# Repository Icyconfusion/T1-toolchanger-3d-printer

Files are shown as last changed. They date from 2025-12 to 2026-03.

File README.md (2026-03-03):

# T1-toolchanger-3d-printer
A toolchanger 3d printer with large format build size and multiple tools for quick, easy multi-material printing that uses marlin as the firmware.


**Note to reviewer:** Since submitting project for review I have updated the BOM (haven't changed products, just updated the prices). The new bom is more than what was in the review, but I have multiple discounts and coupons (that I have also tested) which bring it back down to what I mentioned in review. Thank you :) Also, in regards to firmware, the entire marlin zip folder (must be a zip) is in the firmware folder, but I have copied all files that have been edited and/or relevant (e.g config and ino files) as well into the firmware folder for the reviewer to view. I was instructed to do it this way by other reviewers in similar projects. Thanks.

I made this project as I had been looking to make a 3d printer. I wanted to be able to print in different colours, without the added cost of AMS systems. It was also a good opportunity to learn about using programs like fusion and Kicad, which I have limited experience with, as well as learning about electronic components. I created this project without a guide, using my own ideas to combat problems, with some inspiration from existing products e.g using linear rods.

Note: The assembly files are too large to upload to Github directly. Instead I have put the assembly .step file and .f3z file into a zipped folder named: Printer assembly.zip 

I have also uploaded the same step file as a zipped folder called printer assembly Step.zip, and an STL file called printer assembly STL.zip, just to be sure.

The printer uses a swappable hotend mechanism to dock tools, removing the need to purge filament as in other multi-material systems. The idle toolheads sit on an aluminium extrusion. The X carriage, supported by a V slot extrusion, moves in and attaches to the toolhead, using kinematic couplings for repeatability. A magnetic pogo connector transfers power for the heter and thermistor.


Toolhead:



# **Assembly**

The printer assembly is made by aluminium extrusions forming a cube, with corner connectors for mounting.


To support the Y axis, V slot 2020 aluminium extrusions are used as rails holding a gantry, which in turn supports the X axis.
The Y axis is made up of two carriages, one either side of the X gantry. Each Y carriage uses a gantry plate with wheels to slide along the extrusions, making the Y motion. One carriage is an idler, which the belt loops around a pulley. The other carriage is the stepper motor carriage, which uses a Nema 17 motor to drive the X axis belt. Both carriages hold 90 degree connectors supporting the X extrusion.
Idler:

Stepper carriage:


The X carriage is made of two parts: the main carriage, and the toolhead. The main carriage holds the fan and the extruder stepper motor. When the carriage comes into dock, a fixed arm pushes the extruder idle arm to the side. The filament slides into the extruder,and when docking is complete, the spring loaded, idle arm pushes back into the filament, creating good tension. 


The fan is a 4010 fan, which sits to the side and blows cool air through the heatsink fins and also onto the part/top layer. 


The belt post is located behind the carriage.



The carriage sid of the coupling contains the 6mm smooth rods of the kinematic coupling. This is printed in two pieces, so that the rods can be put into grooves before the 'lid' of the coupling closes through screws. The pogo connector is also housed here.



The toolhead uses steel balls to push into the kinematic coupling. The male side of the pogo connector is on the toolhead.


The hotend mounts to the two holes in the middle.

The Z axis involves the motion of the bed up and down. Originally, I had planned to move the hotend throughout all 3 axis, and the bed was fixed. I encountered many issues with reliably and consistently achieving motion of the hotend without the risk of flexing, so I pivoted to a bed Z axis. A leadscrew and two 8mm linear rods are used on each side, connected to an aluminium profile by a nut block and 3d printed clamps.


The bed frame is a square made of aluminium extrusions, held together by 90 degree corner connectors. The 6mm aluminium print bed sits on top of that, threaded into T nuts in the profiles.





Toolchanging mechanism. Tools are held on the toolchanger rack, installed with T nuts on an aluminium profile. L shaped hooks hold the tools in place, using knobs on the tools.Wwhen the tool slides in sideways, the knob/tool will be separated from the carriage by the hook Then the carriage will move backwards, detaching the magnets in the connectors, and pulling the tool off the rack. To attach, it simply presses the carriage onto the tool, pushes it back and slides out. The magnets used in the connector and the balls should be enough to hold the tool in place, but in the event it is not, I can use print in place function in slicers to add in even stronger magnets in the centre (only if current magnet setup isn't strong enough - unlikely).




# **Electronics**


The printer uses a PCB motherboard to mount components including the MCU (Mega 2560), stepper drivers, LCD headers, and heater terminals. I decided on a 24v power supply as it was compatible with my heater. To give power to the PCB, I used a meanwell 24v 360W power supply.


This connects through wires to screw terminals on the board, which then distribute power across the PCB. Because of the power requirements, I decided to use a 4 layer PCB as I couldn't route signal traces through the power and GND traces. Using a 4 layer PCB is necessary to the peojwct due to the power layout of drivers, making signal traces impossible without a 3rd and 4th layer. The top and bottom layers of the PCB are the power layers. Power runs from the PSU input to the heater screw terminal, and throughout the board. It is converted to 5v through a buck converter. The Hotend heater is powered through a screw terminal, and controlled by the mosfet next to its terminal. The hotend fan is controlled by a header, it is in an always on state.


The signal traces from the drivers, limit switches, thermistor and LCD are on the second and third layers.


The MCU is a mega 2560. I chose this because of its large availability of pins, enabling future upgrades and fitting all components. The stepper drivers are A4988s, which have microstepping up to 1/16. All microstep pins are connected to 5v, making the configuration 1/16. The limit switches, thermistor and lcd connect to headers.

The power for the stepper drivers is 24v. To reduce the effect of spikes, a small 100nf capacitor is used between the 24v and gnd supply of each driver. For larger spikes, a 100 uF capacitor is also placed between 24v and gnd of each driver.


The LCD is the main user interface of the printer. I am using the BIGTREETECH TFT35 V3.0 Touch Screen from BigTreeTech which has wifi capability and is 3.5". I chose this LCD as it only uses 2 pins on the MCU (TX and RX), has an SD card, and is touchscreen. It is possible to mount the LCD separately to the motherboard, and run a cable between the two, enabling you to set it up however you like. LCD Header:


The Motherboard and PSU are not fixed components to the printer and can be placed wherever suitable as long as cabling reaches. (I already have a case at home for my pcb from older projects).

### Schematic







# **Firmware**

The printer uses the latest version of marlin firmware, which enables the use of G-code. The general firmware of the printer is fairly standard and straightforward, as marlin is just configured to the printer dimensions and layout. The firmware has been edited to match the printer configuration with things like pin usage, limits, dimensions, and rough speeds/acceleration (these will require testing following assembly).

However, the printer being a toolchanger introduces a unique element to the firmware in the connection and preparation of multiple toolheads. To simplify firmware and general electronics, I decided on having 'hot-swappable' toolheads that connect through pogo connectors. Because of this, the firmware views it as one hotend when it comes to heating the temperature monitoring. In this aspect, the printer appears as standard. To facilitate toolchanges though, special G-code is required to move the carriage into specific positions. This is most effectively achieved through pre and post g-code in the slicer per tool. The main idea of the toolchange G-code is that the empty carriage moves into alignment with the passive tool, moves forward to latch on, and then returns to the print area. When returning a tool to the standby dock, it is the same idea in reverse, where it moves into a specific position, pushes the tool into the dock, and returns to pick up another tool. This is the series of G-code to paste into the slicer pre and post processing:

Pre:

M1 X(Tool X value) Y440 F6000

M1 X(Tool X value) Y480 F2000

M1 X(Tool X value + 60) Y480 F2000

M1 X(Tool X value + 60) Y440 F2000

Post:

M1 X(Tool X value + 60) Y440 F6000

M1 X(Tool X value + 60) Y480 F2000

M1 X(Tool X value) Y480 F2000

M1 X(Tool X value) Y440 F1000

The X values are unique to each tool, as tools are docked in order across the X axis. Specific values will require precise tuning with manual adjustment following assembly to ensure correct alignment of the coupling, so values are not possible now, but the spacing between docks will be roughly 100mm.

Breaking down this G-code, the carriage moves into a position hovering off of the dock, in X alignment. The carriage then slowly pushes into the docked tool in the second G-code command. At this point, the kinematic coupling engages, ensuring alignment, and the magnetic clamp and pogo connectors attach, preparing the tool for printing. The third G-code command moves the carriage and new tool to the right, out of the dock, before returning to the print area with the fourth command. this process occurs in reverse for the docking of the tool/post G-code series.

# **BOM**
### CAD

| Quanity | Name |  Picture |
| ---| ---|---  |
| 1 | New X carriage |
| 1 (per tool) | Toolhead |
| 4 | Z axis bearing clamp |
| 2 | Z stepper bracket |
| 4 | Z rod holder |
| 2 | Nema 17 parallel mount| 
|4 | plain limit switch bracket| 
|4| z rod top bracket|
|1| toolchanger rack| 

### PCB
4 layer PCB that is 230x135mm:

Layers 1 and 4 make up the power layers, 24v (a small bit of 5v) and GND. This was a requirement due to the large power draw of the machine, requiring thick traces that took up a lot of room. I tried routing the pcb using only 2 layers, but this was not possible. Layers 2 and 3 are signal layers.

### Parts

1x BTT TFT35 V3.0 LCD

1x Arduino Mega 2560

6x Limit switch

4x 8mm smooth rods, 500mm length

1x 6mm smooth rod, 500mm length

6x 8mm steel balls

15x 2020 Aluminium profile 500mm length

2x 500mm T8 8mm lead leadscrew 

2x Anti-backlash leadscrew nut

2x Hotend (CR6-SE)

1x 4010 Fan

1x GT2 Kit

2x Aluminium Profile 90 degree connector

8x Aluminium profile corner connector

1x PSU (24v 360w+)

2x Screw terminals

1x N-channel Mosfet

1x 2x18 Pin header

16x Female pin headers

42x Male pin headers

5x A4988 Stepper drivers

1x 20 AWG Wire

1x 12 AWG Wire

3x Pogo connectors

1x 3d print bed

4x LM8UU bearing

2x Angular bearing

1x DC-DC step down Buck Converter

110x T Nuts

8x L Bracket

5x 100 nF Capacitor

5x 100 µF capacitor

1x Spring

6x Leadscrew fixing block

40x M5 screws and nuts

40x M4 screws and nuts

2x Shaft coupler 5x8mm

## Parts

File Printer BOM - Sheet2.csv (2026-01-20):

Product name | Quantity | Description | Seller | Cost (USD) | Link
LCD | 1 | 3.5" TFT LCD by BigTreeTech for the printer menu/UI. The main interface of the printer | Aliexpress | 13.99 | https://www.aliexpress.com/item/1005005854372603.html?curPageLogUid=qZsDAdC5Y4Xx
Arduino Mega | 1 | Arduino mega 2560, the MCU of the printer. Handles the entire printer and connects to the motherboard/PCB. Runs Marlin firmware | AliExpress | 14.53 | https://www.aliexpress.com/item/1005006718820087.html?curPageLogUid=aNr4dMdpbXv9
Limit switch | 6 | Limit switches for the end stops of each of the three axis, a min and max, for a total of 6 | AliExpress | 2.5 | https://www.aliexpress.com/item/1005009049556408.html?curPageLogUid=5GZwXXJUzPi6
NEMA 17 stepper motor | 5 | 42x42 NEMA 17 stepper motors for controlling the printer. 1 each for the x and y axis. 2 for the z axis and 1 for the extruder | Temu | 35.32 | https://www.temu.com/goods.html?goods_id=601100099700138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
Hotend | 2 | The filament nozzle device. One is required per toolhead. The Cr6-SE is a cheap but effective hotend including a thermistor | Temu | 7.54 | https://www.temu.com/goods.html?goods_id=601099512788933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
Buck Converter | 1 | DC-DC step down Buck converter to get 5V logic on the PCB from the 24V PSU input to power stepper drivers and LCD | AliExpress | 2.52 | https://www.aliexpress.com/item/1005005671924823.html?curPageLogUid=Uh3WaYBHiqdz
PSU | 1 | 24V 350W PSU. Plugs into wall, and has terminal blocks for DC output | AliExpress | 17.57 | https://www.aliexpress.com/item/1005010130797577.html?curPageLogUid=jA1pArEAkMDu
Screw terminals | 2 | High current, 7.62mm pitch 2 pin screw terminals for PSU input to PCB and hotend heater connection | AliExpress | 1.64 | https://www.aliexpress.com/item/1005003493308832.html?curPageLogUid=nwVTtRybSPT9
Mosfet | 1 | Logic level IRLZ44N MOSFET for controlling hotend | AliExpress | 3.2 | https://www.aliexpress.com/item/32812805504.html?curPageLogUid=0RdDFr5byskR
2x18 Pin header | 1 | 2.54mm header socket for connecting the MCU to the PCB. One 2x18 pin socket | AliExpress | 1.32 | https://www.aliexpress.com/item/1005008966856219.html?curPageLogUid=X4LfqQCw2NW1
Female pin headers | 16 | 2.54mm female headers to connect stepper drivers and MCU to the PCB. Need 15 of 8 pin sockets and 1 10 pin socket. | AliExpress | 5.05 | https://www.aliexpress.com/item/4000979967513.html?curPageLogUid=btaibAQnoEML
Stepper drivers | 5 | The A4988 Stepper drivers control the stepper motors. One per motor | Temu | 5.44 | https://www.temu.com/au/5pcs-a4988-stepper--module-with-heat-sink-compatible-for-3d-printer-cnc-machine-robotics-heavy-duty-stepper-driver-board-low-voltage-o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
Pogo connectors | 2 | A pair of magnetic connectors for transferring power and data between the toolhead and the X carriage (to the motherboard). One female is required for the carriage, one male is required per toolhead | AliExpress | 9.27 | https://www.aliexpress.com/item/1005009493408885.html?curPageLogUid=1UtYP8iZN0DZ
4010 Fan | 4 | Fans for cooling the hotend, print layer and idle hotends | AliExpress | 3.55 | https://www.aliexpress.com/ssr/300000512/BundleDeals2?productIds=1005006317979634:12000036739932434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
100 µF capacitor | 5 | Larger, 50V 100µF electrolytic capacitor to prevent large spikes to stepper driver | AliExpress | 3.35 | https://www.aliexpress.com/item/1005006103573862.html?curPageLogUid=iLWVM9XPXba2
6mm smooth rod | 1 | The 6mm smooth rod is cut up into small lengths ~2cm. Six lengths are used to form 3 points of contact in a kinematic coupling, which is the basis for the tool changer mounting. There is roughly 120mm of rod per tool | Temu | 3.93 | https://www.temu.com/goods.html?goods_id=601103578228025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
8mm steel balls | 6 | The steel balls make up the tool head side of the coupling, sliding into the pairs of rods to make a kinematic coupling. Three balls are required per tool | Temu | 1.96 | https://www.temu.com/au/50pcs-8mm-high-carbon-steel-bearings-polished-precision-hardened-for-industrial-and-bicycle-bearing-additions-g-606550127122263.html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
Aluminium profile V slot | 10 | 500mm 2020 Aluminium profiles make up the support frame. They form a cube to mount axis and standby tools. | Temu | 69.15 | https://www.temu.com/goods.html?goods_id=601101427050232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
Aluminium profile T slot | 6 |  | Temu | 37.99 | https://www.temu.com/au/6pcs-500mm-19-7inch-t-slot-2020-aluminum-profile-extrusion-european-standard-anodized-linear-guide-rail-for-3d-printer-parts-and-cnc-m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
Leadscrew | 2 | 500mm leadscrews with 8mm lead, 2mm pitch, T8. Allow the motion of the Z axis | AliExpress | 14.44 | https://www.aliexpress.com/item/1005007979792529.html?curPageLogUid=WSR8yxMhOTI0
Anti-backlash leadscrew nut | 2 | The nut block for attaching leadscrews to the aluminium profiles that support the Z axis/Bed | AliExpress | 3.79 | https://www.aliexpress.com/item/1005006826718120.html?curPageLogUid=65pwVz6xzyEr
Corner bracket | 8 |  | Aliexpress | 5.13 | https://www.aliexpress.com/item/1005008505134767.html?curPageLogUid=mfwyOGxZSpUS
90 degree bracket | 2 |  | Temu | 3.69 | https://www.temu.com/goods.html?goods_id=601099557078822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
Gantry plate | 3 |  | Aliexpress | 17.28 | https://www.aliexpress.com/item/1005007487312327.html?curPageLogUid=KoJDc8OpkMHw
Lm8UU | 4 |  |  | 5.8 | https://www.aliexpress.com/item/1005008514894735.html?curPageLogUid=YU3c9D1OQmkO
8mm smooth rod | 4 |  | Aliexpress | 19.89 | https://www.aliexpress.com/item/32910995390.html?curPageLogUid=iklCxlcIxuPD
Shaft coupler | 2 |  | Temu | 2.85 | https://www.temu.com/goods.html?goods_id=601104056754749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
3d print bed | 1 | 6mm Cast Alloy build plate. This is the structural element of the print bed, a surface is added e.g PEI or painters tape and the bed is complete | AliExpress | 57.19 | https://www.aliexpress.com/item/1005010341219518.html
Leadscew fixing block | 2 | A bearing block that holds the leadscrew in place | AliExpress | 4.11 | https://www.aliexpress.com/item/1005003074750605.html?curPageLogUid=PqT2uBu0W3p9
M5 nut | 40 | T Nut for fastening M5 screws | AliExpress | 4 | https://www.aliexpress.com/item/1005007383347166.html?curPageLogUid=xpPeUXxTGQnY

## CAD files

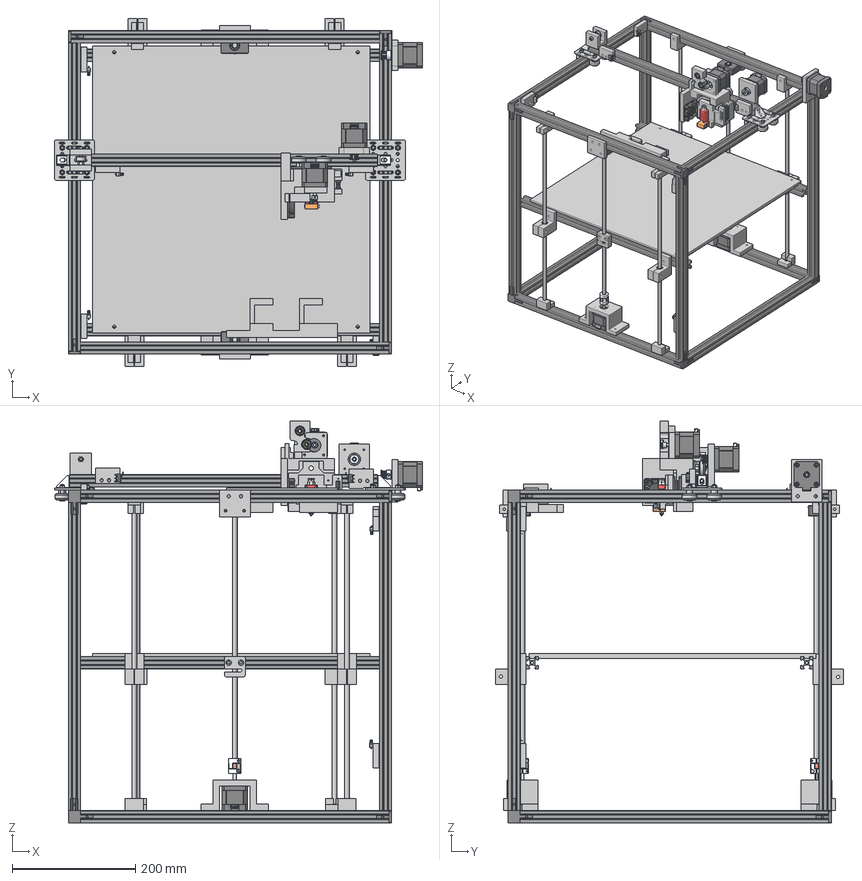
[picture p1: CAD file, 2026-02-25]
New+assembly.stp
597.6 x 565.0 x 652.1 mm
aluminum extruded rail 20 x 20 3 way ends x 8
V-Slot Gantry Plate 20mm v1 x 3
Low Profile Screw M5 v1 x 12
Nylon Insert Lock Nut M5 v1 x 12
Aluminum Spacer 6mm v1 x 6
Eccentric Spacer 6mm v1 x 6
Ball Bearing 5 x 16 x 5 v1 x 24
Precision Shim 8 x 5 x 1 v1 x 12
Xtreme Solid V Wheel v1 x 12
90 Degree corner connector x 2
Middle part x 5
Bottom plate x 5
Top plate x 5
Philips M3X30 x 20
JST-S6B-PH-K-S x 5
Bearing x 10
Stepper shaft x 5
Z-coupler x 2
8mm Acme Anti Backlash Nut Block x 2
3.Linear Bearing-LM8UU x 4
GT2 20T5B_dz2020 x 2
JIS B 1180 - M5x40 C Steel 4.6 Plain
DIN EN ISO 4032 - M5 Steel 6 Plain x 2
Limit_Switch_SPDT_sim_roller x 6
688Z x 2
90991A124_18-8 Stainless Steel Button Head Torx Screws x 4
T-Slot Nut (1) x 4
92605A099_Stainless Steel Flat-Tip Set Screw x 2
hobbed bush 5mm shaft
01 - Anel Externo x 2
02 - Anel Interno x 2
04 - Esfera de Aço 3mm x 16
05 - Gaiola x 4
06 - Pino x 16
03 - Capa Lateral x 4
MK8 Hotend
4010 Fan

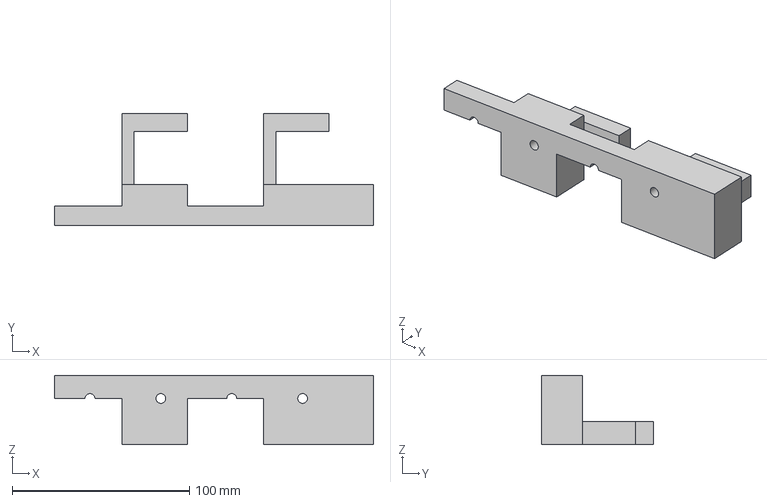
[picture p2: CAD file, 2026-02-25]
CAD/Toolchanger rack.step
180.0 x 63.0 x 39.0 mm

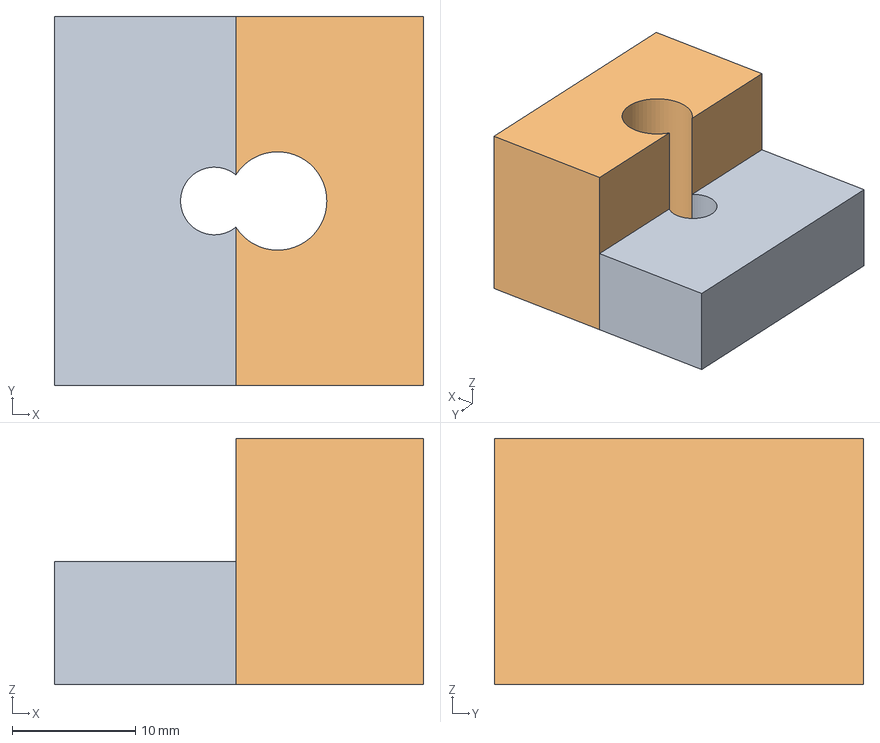
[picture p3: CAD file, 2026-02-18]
CAD/Z smooth rod holder.step
30.0 x 30.0 x 20.0 mm

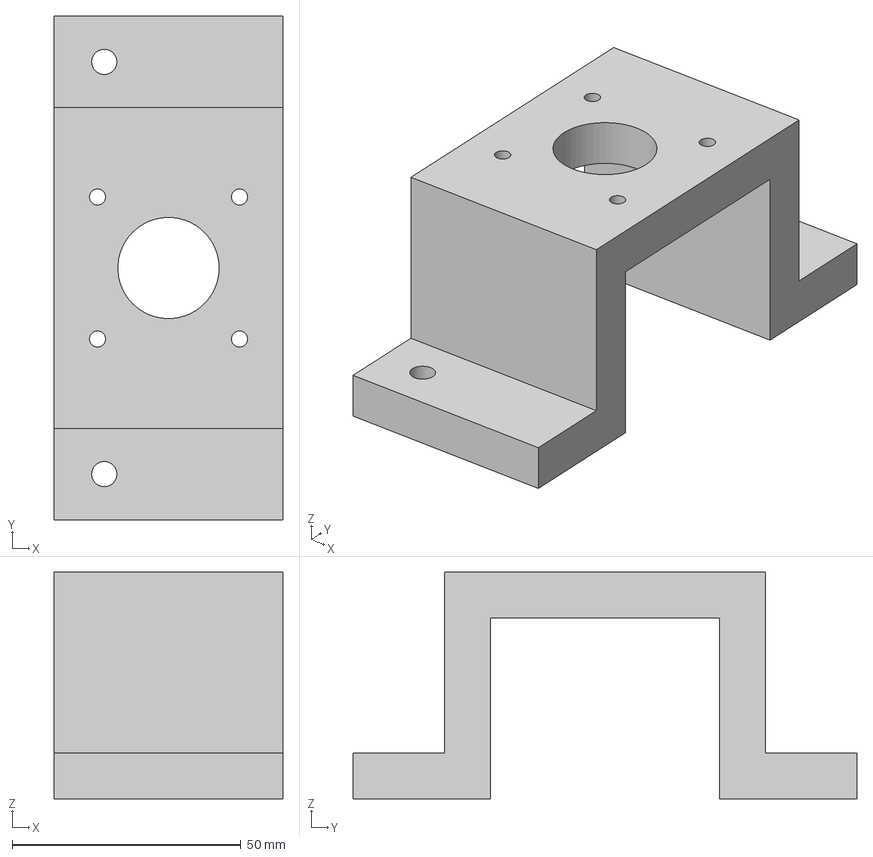
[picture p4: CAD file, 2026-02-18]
CAD/Z stepper bracket.step
50.0 x 110.0 x 49.5 mm

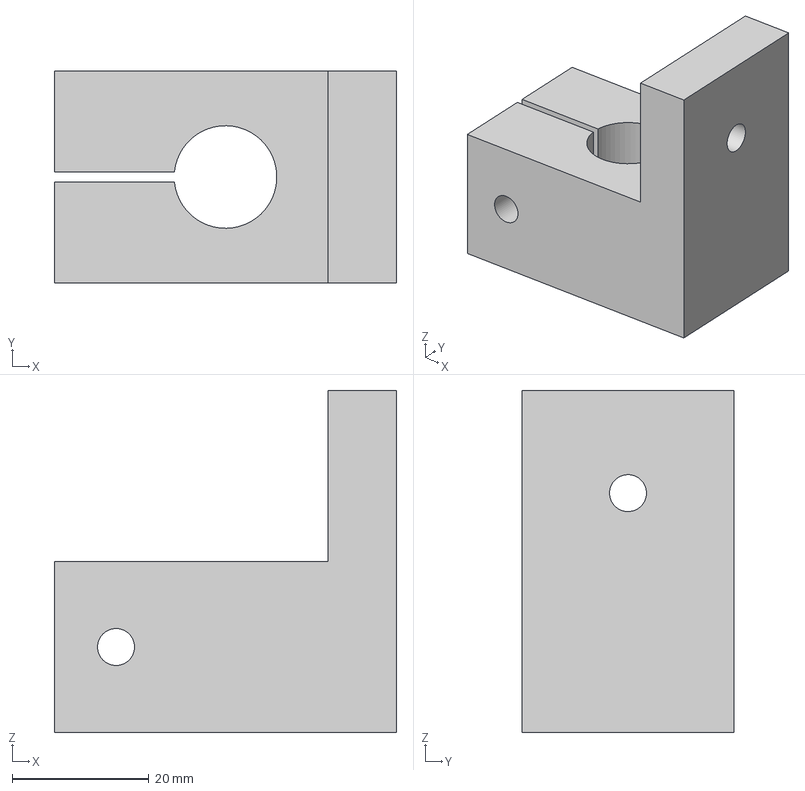
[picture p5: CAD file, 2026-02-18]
CAD/Z axis bearing clamp.step
50.0 x 31.0 x 50.0 mm

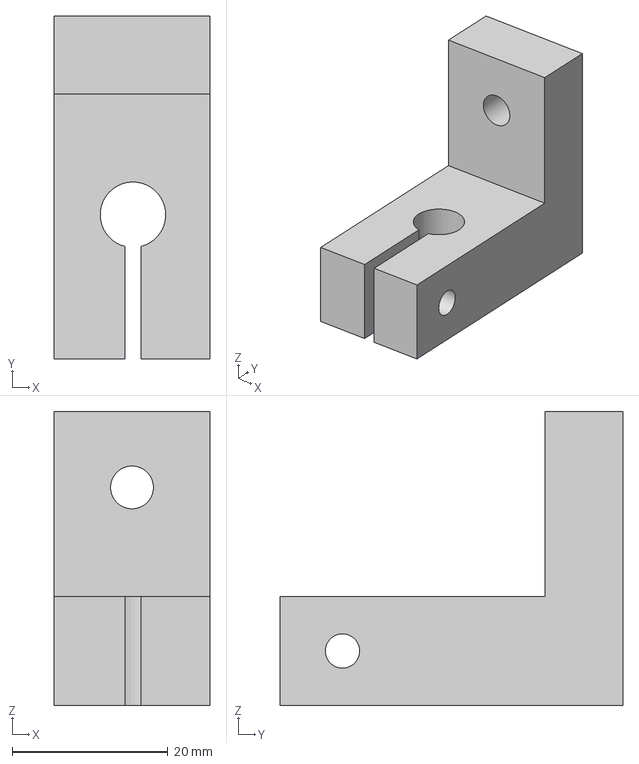
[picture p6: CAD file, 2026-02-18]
CAD/Z rod top bracket.step
20.0 x 44.0 x 37.7 mm

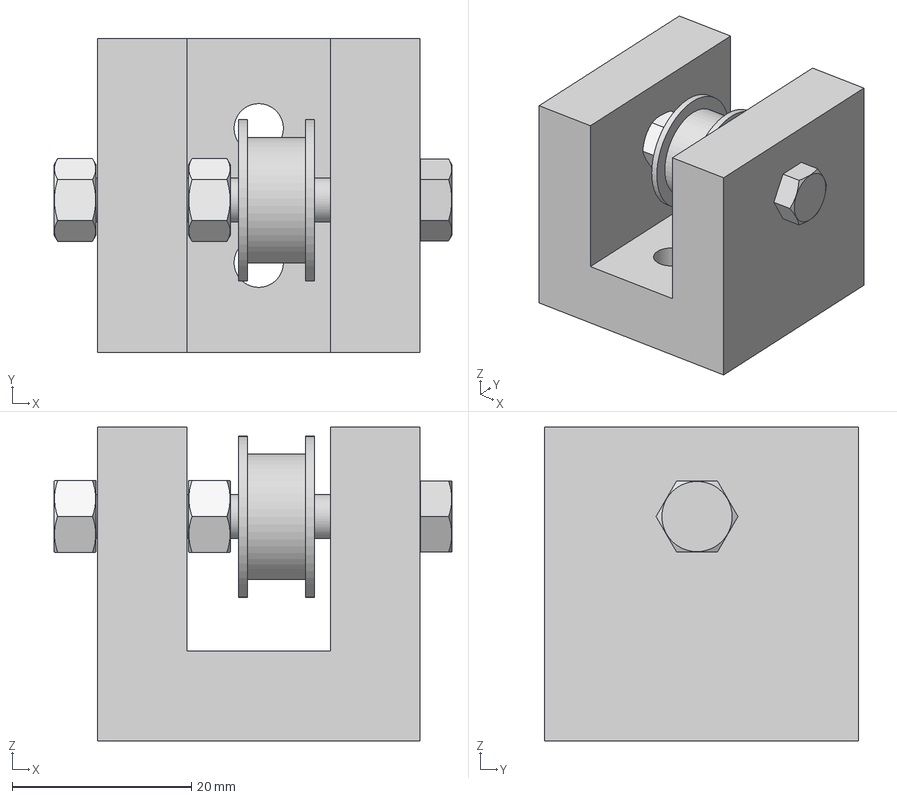
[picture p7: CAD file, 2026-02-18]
CAD/Y axis idle bracket.step
44.4 x 35.0 x 35.0 mm
JIS B 1180 - M5x40 C Steel 4.6 Plain
DIN EN ISO 4032 - M5 Steel 6 Plain x 2

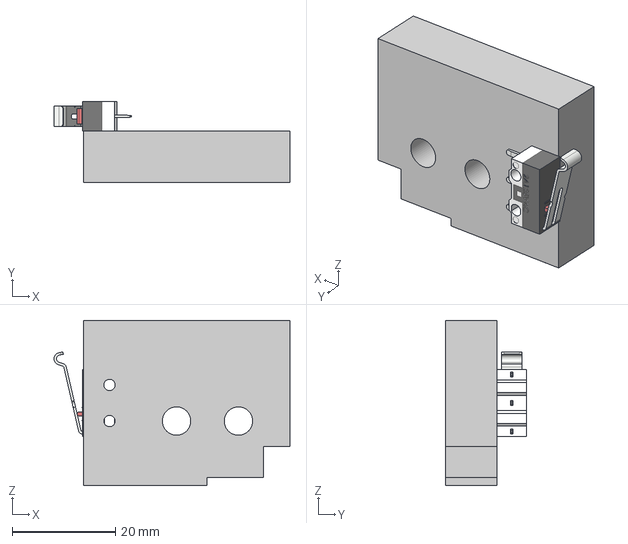
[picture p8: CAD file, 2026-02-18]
CAD/plain Limit switch bracket.step
45.8 x 15.8 x 32.0 mm

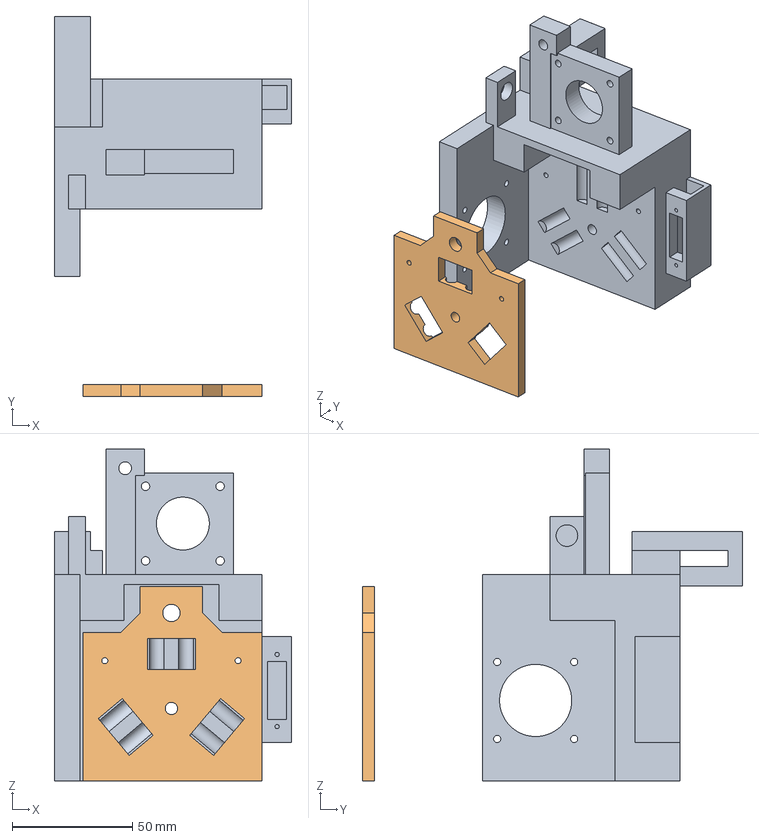
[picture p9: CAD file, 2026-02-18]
CAD/New+x+carriage+print.stp
98.7 x 158.0 x 138.0 mm

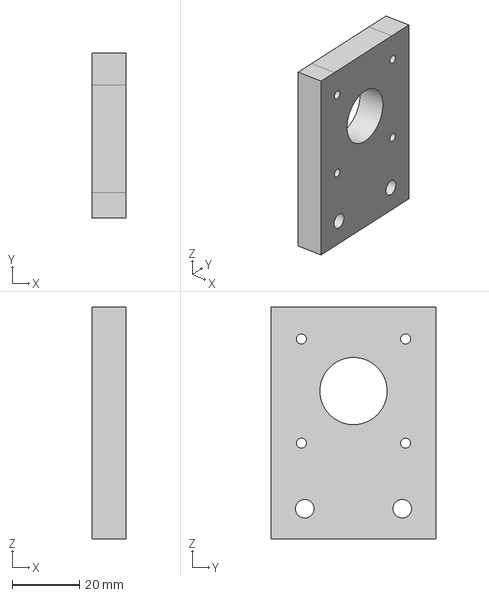
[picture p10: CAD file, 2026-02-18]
CAD/Nema 17 motor parallel mount.step
10.0 x 49.0 x 69.0 mm

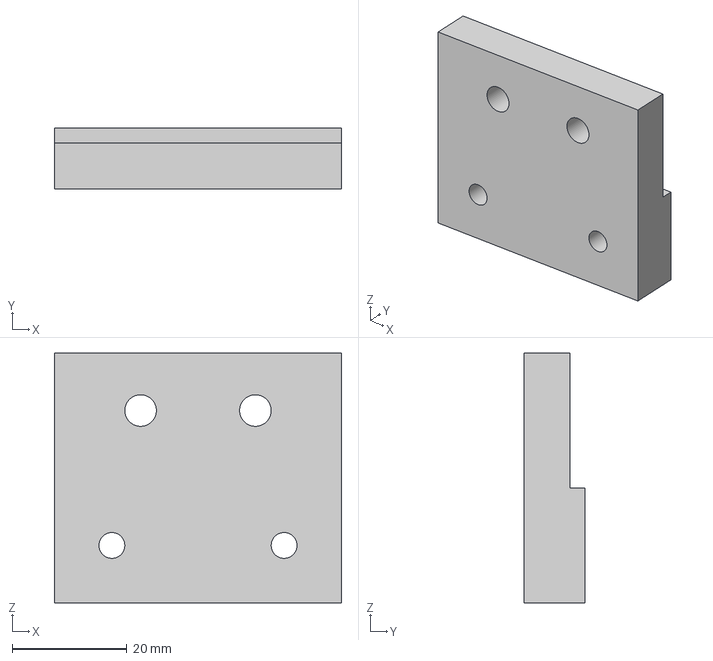
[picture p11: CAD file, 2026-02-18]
CAD/Z leadscrew bracket.step
50.0 x 10.6 x 43.5 mm

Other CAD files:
New assembly.f3z

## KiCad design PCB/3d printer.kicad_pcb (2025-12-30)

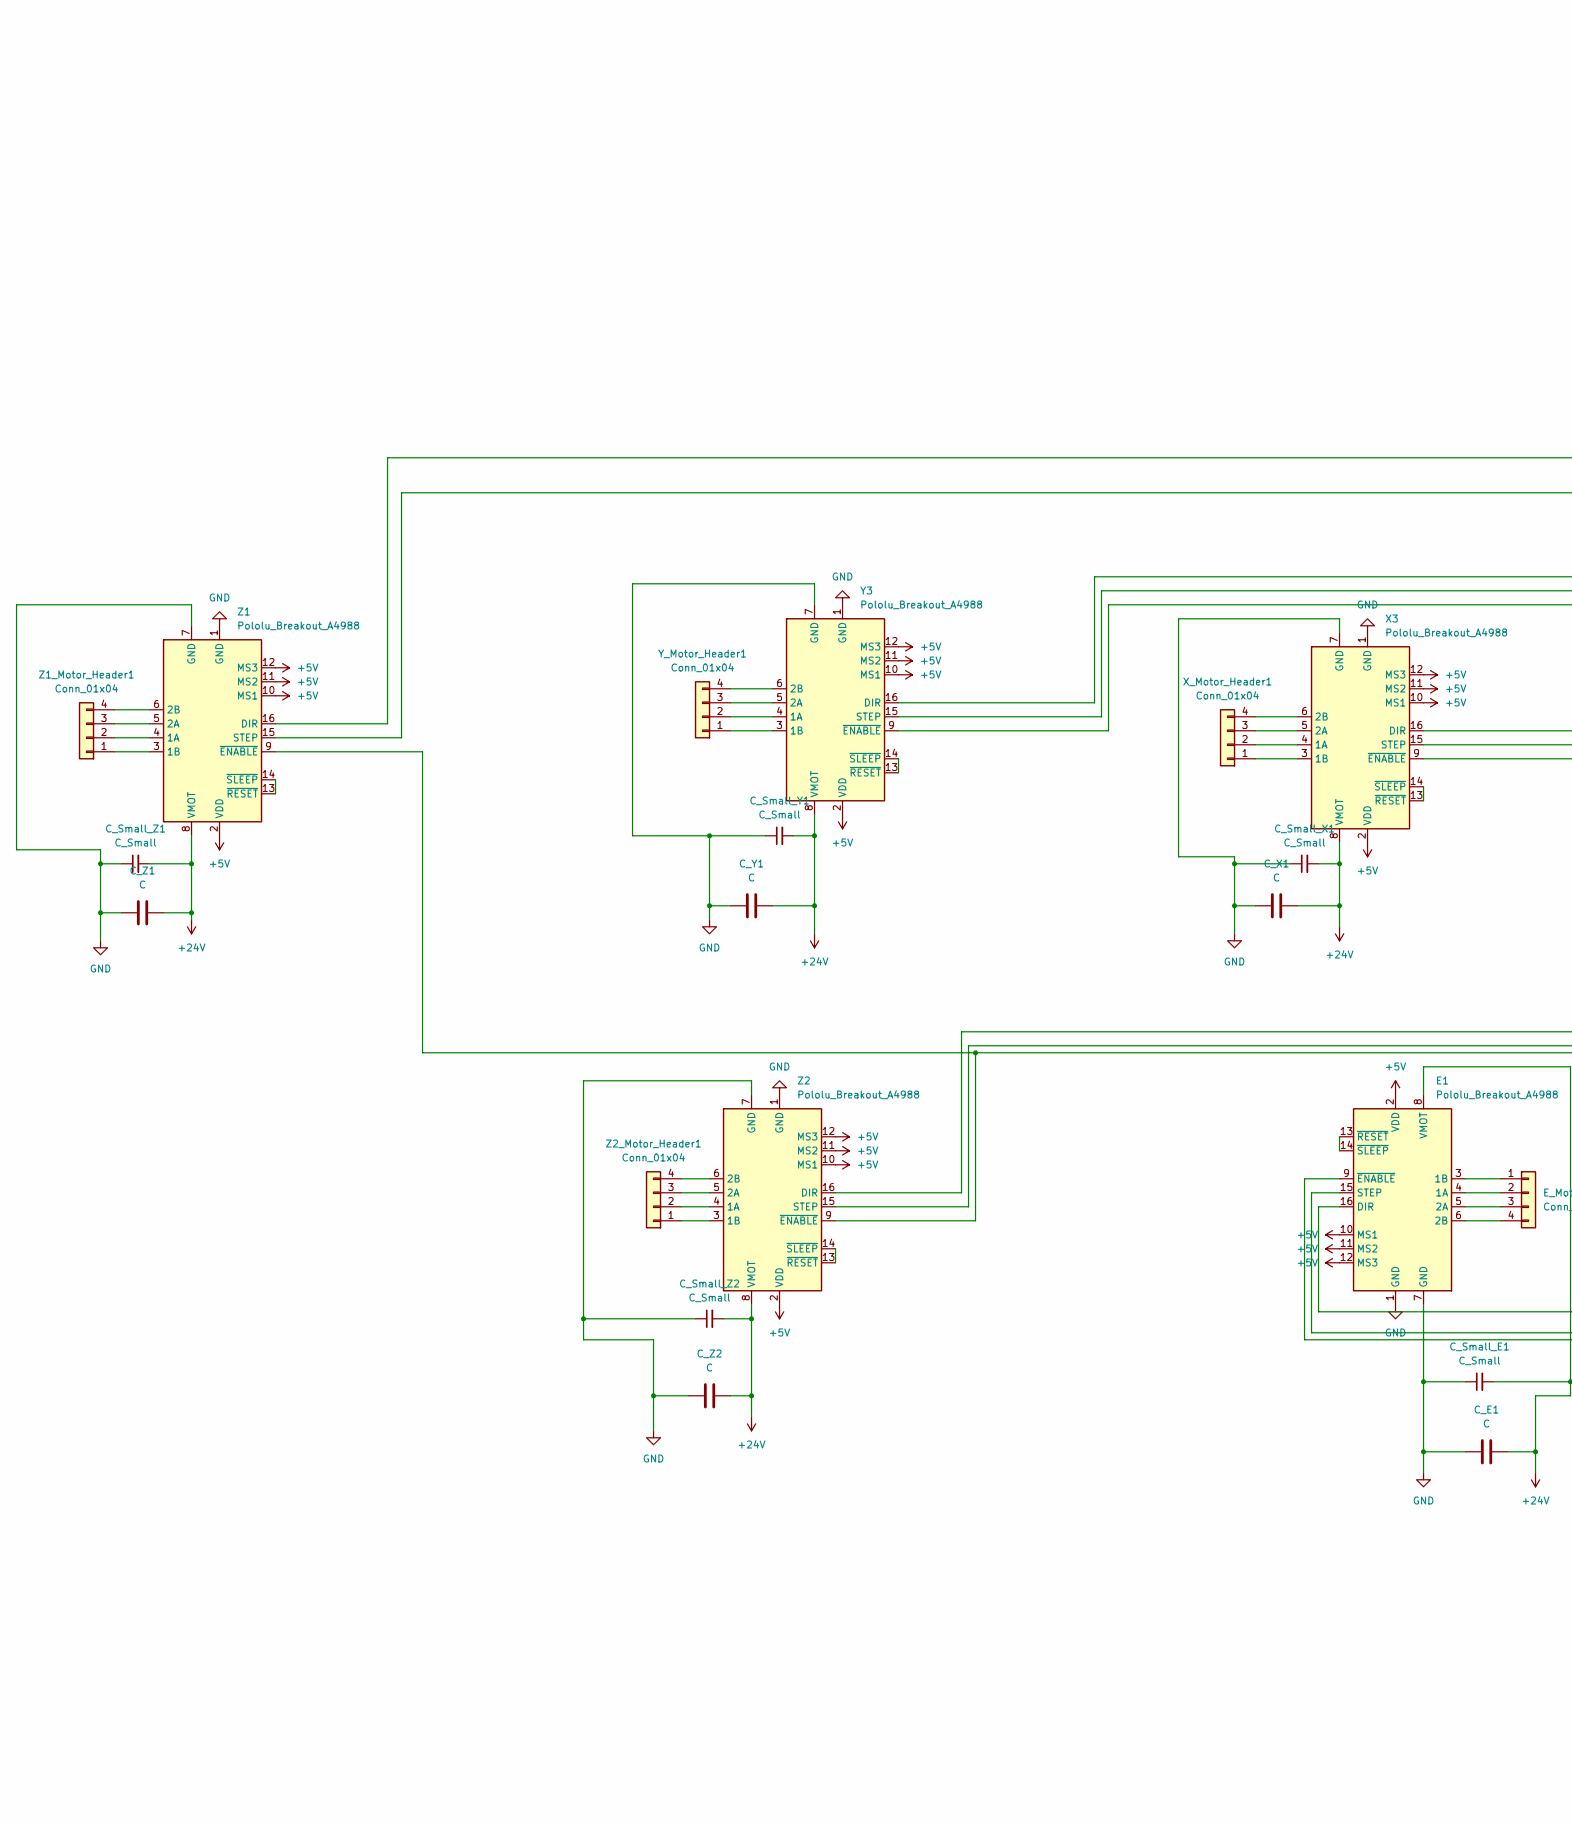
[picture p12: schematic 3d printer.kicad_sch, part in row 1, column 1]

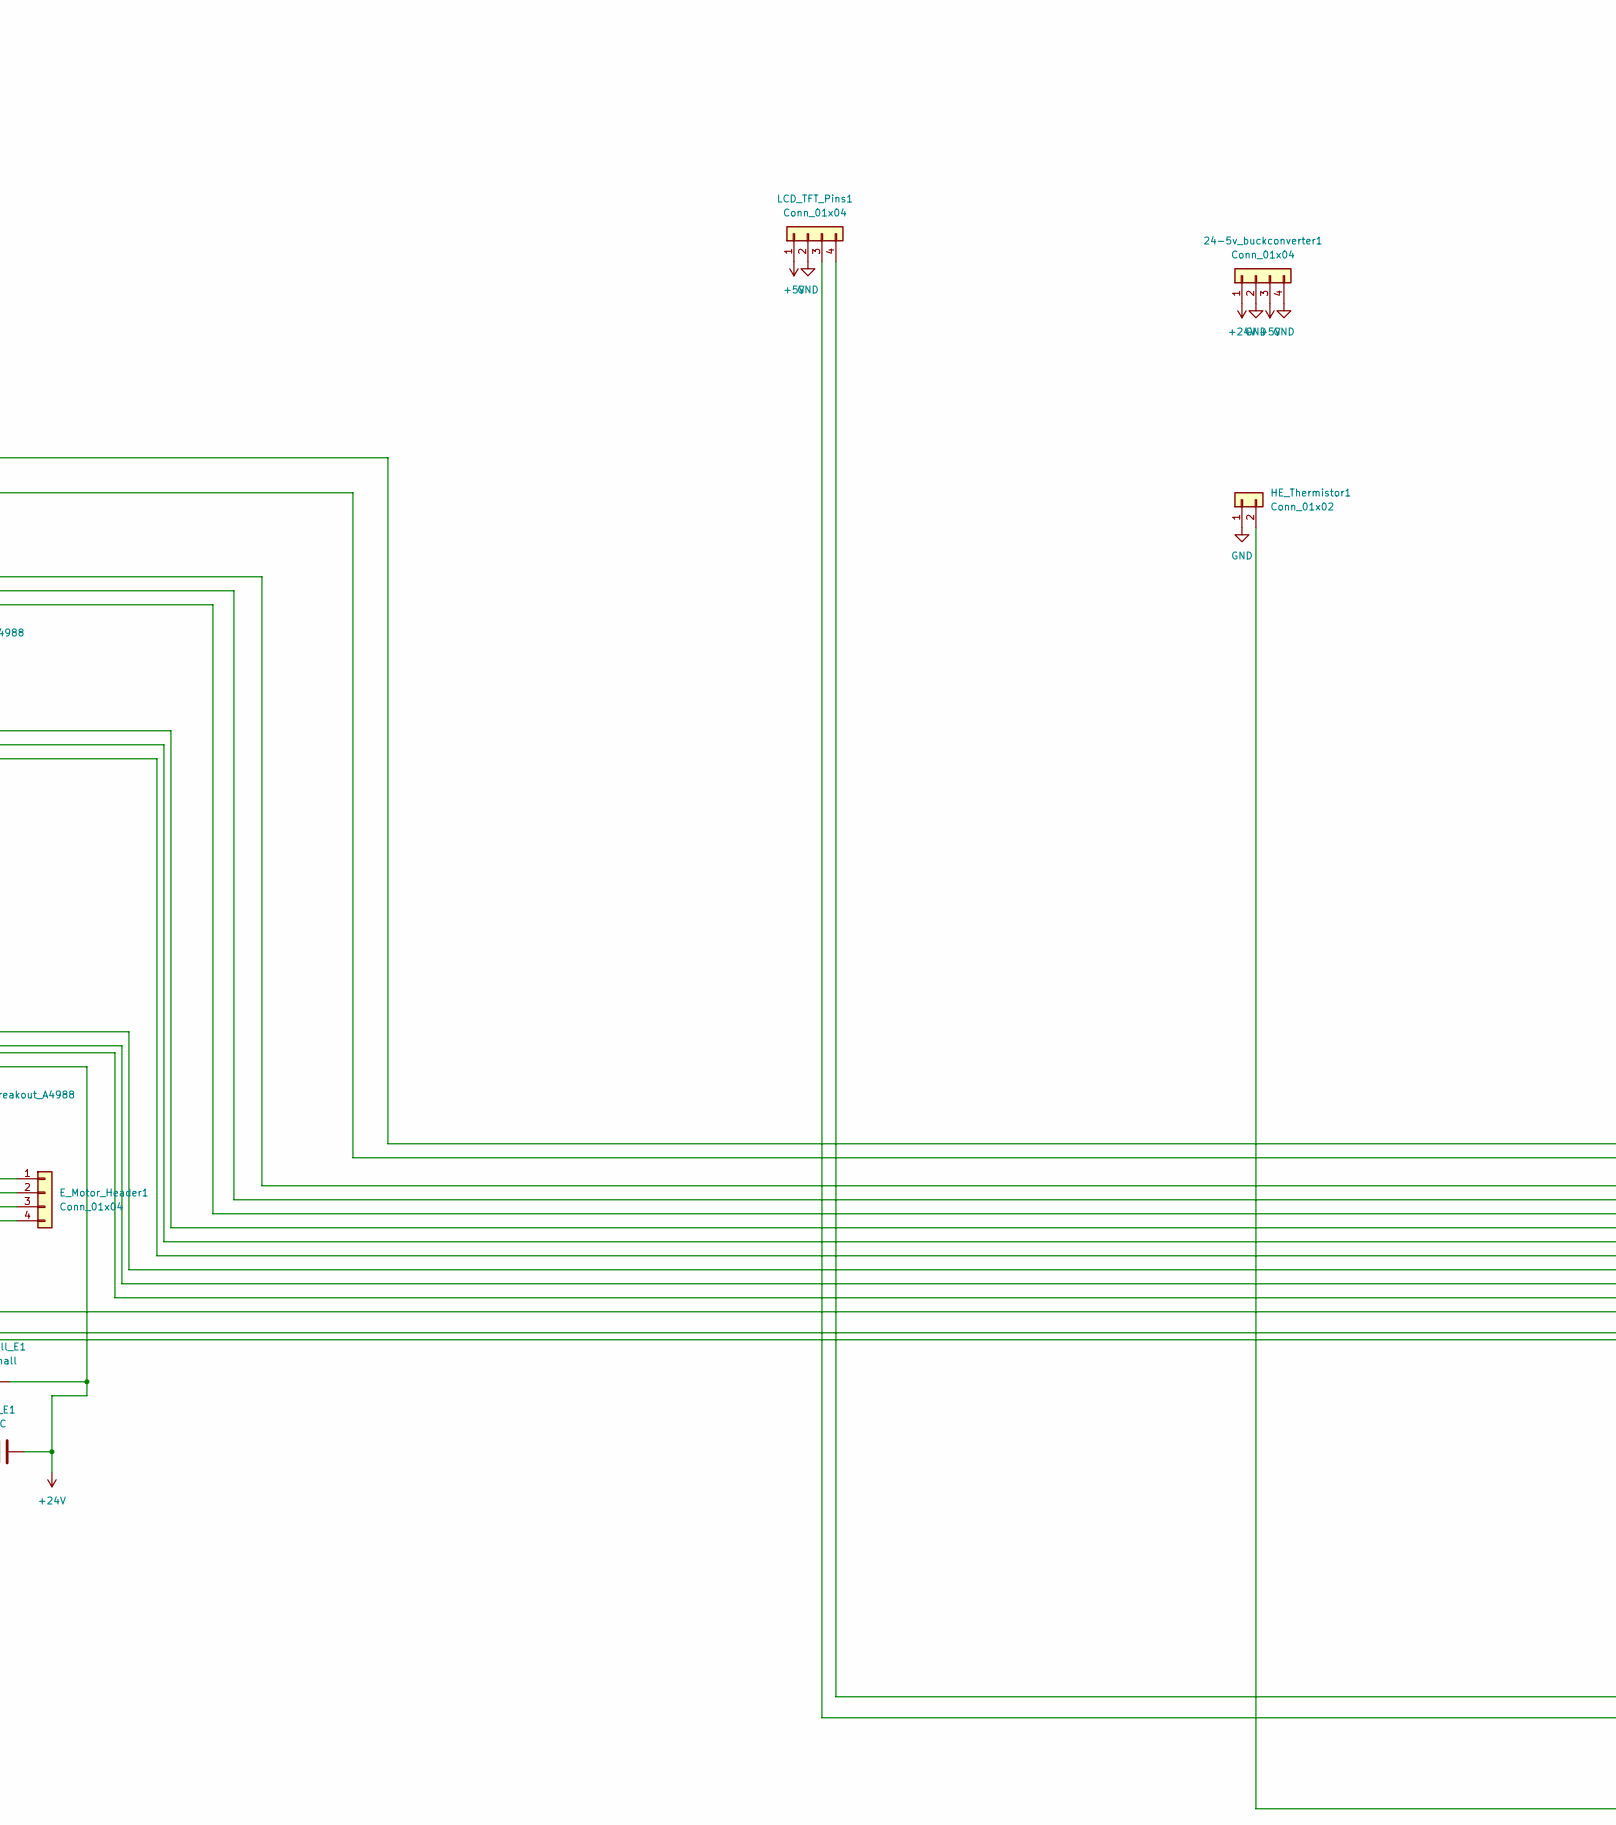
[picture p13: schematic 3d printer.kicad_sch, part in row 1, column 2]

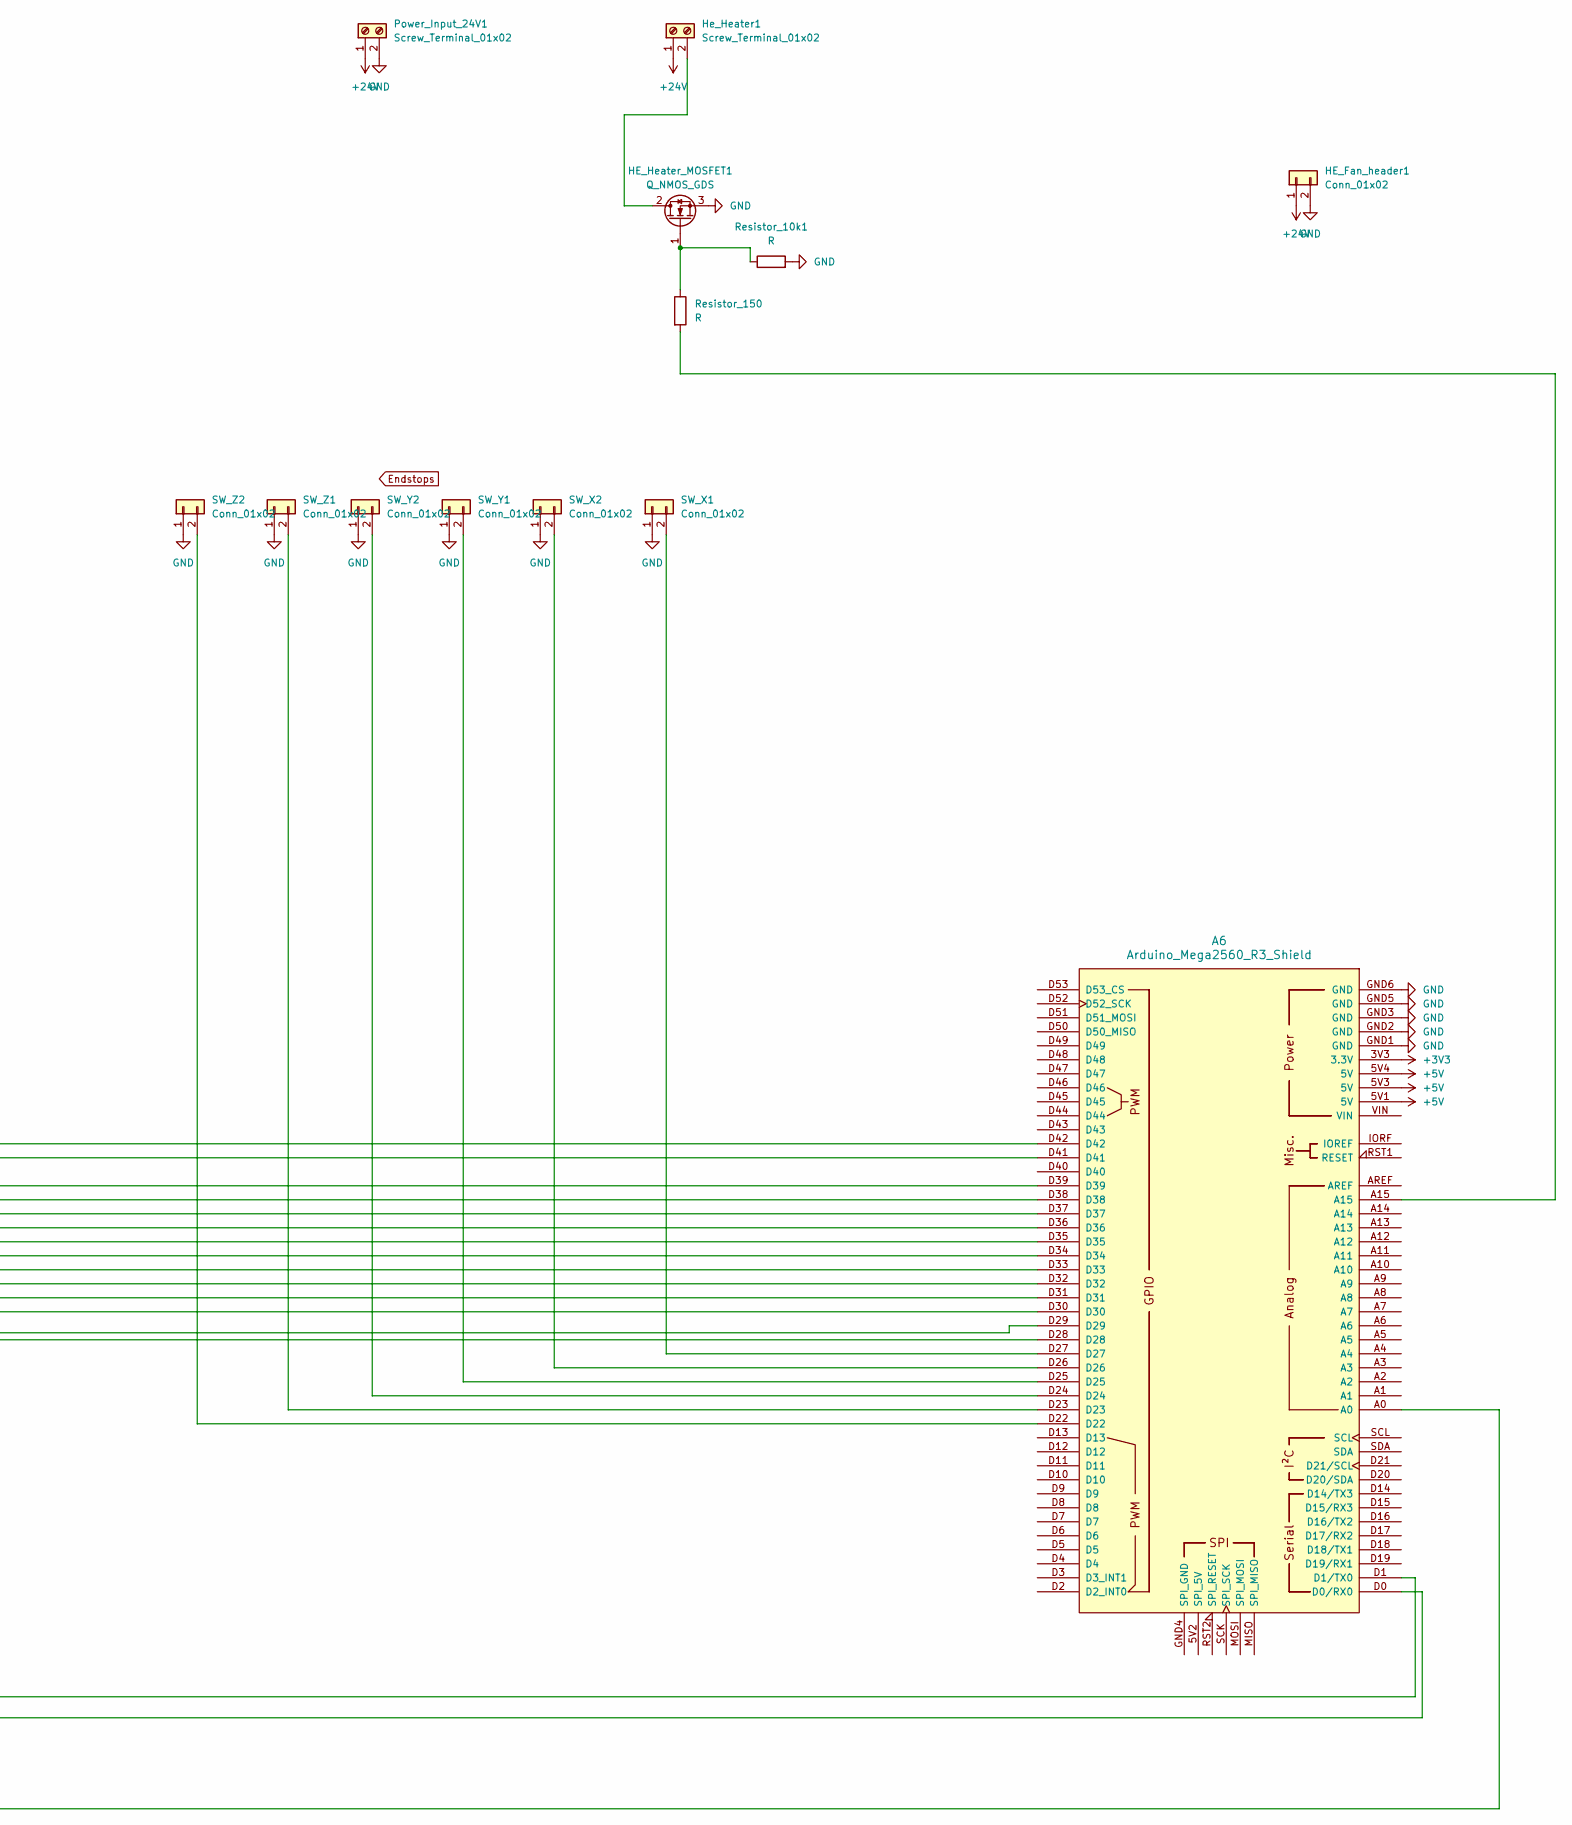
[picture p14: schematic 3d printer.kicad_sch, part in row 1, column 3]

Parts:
24-5v_buckconverter1: Conn_01x04; PinHeader_1x04_P2.54mm_Vertical
A6: Arduino_Mega2560_R3_Shield
C_E1: C; CP_Radial_D8.0mm_P5.00mm
C_Small_E1: C_Small; C_Disc_D5.0mm_W2.5mm_P5.00mm
C_Small_X1: C_Small; C_Disc_D5.0mm_W2.5mm_P5.00mm
C_Small_Y1: C_Small; C_Disc_D5.0mm_W2.5mm_P5.00mm
C_Small_Z1, C_Small_Z2: C_Small; C_Disc_D5.0mm_W2.5mm_P5.00mm
C_X1: C; CP_Radial_D8.0mm_P5.00mm
C_Y1: C; CP_Radial_D8.0mm_P5.00mm
C_Z1, C_Z2: C; CP_Radial_D8.0mm_P5.00mm
E1: Pololu_Breakout_A4988; Pololu_Breakout-16_15.2x20.3mm
E_Motor_Header1: Conn_01x04; PinHeader_1x04_P2.54mm_Vertical
HE_Fan_header1: Conn_01x02; PinHeader_1x02_P2.54mm_Vertical
HE_Heater_MOSFET1: Q_NMOS_GDS; TO-220-3_Vertical
HE_Thermistor1: Conn_01x02; PinHeader_1x02_P2.54mm_Vertical
He_Heater1: Screw_Terminal_01x02; TerminalBlock_RND_205-00232_1x02_P5.08mm_Horizontal
LCD_TFT_Pins1: Conn_01x04; PinHeader_1x04_P2.54mm_Vertical
Power_Input_24V1: Screw_Terminal_01x02; TerminalBlock_RND_205-00232_1x02_P5.08mm_Horizontal
Resistor_10k1, Resistor_150: R; R_Axial_DIN0207_L6.3mm_D2.5mm_P7.62mm_Horizontal
SW_X1, SW_X2: Conn_01x02; PinHeader_1x02_P2.54mm_Vertical
SW_Y1, SW_Y2: Conn_01x02; PinHeader_1x02_P2.54mm_Vertical
SW_Z1, SW_Z2: Conn_01x02; PinHeader_1x02_P2.54mm_Vertical
X3: Pololu_Breakout_A4988; Pololu_Breakout-16_15.2x20.3mm
X_Motor_Header1: Conn_01x04; PinHeader_1x04_P2.54mm_Vertical
Y3: Pololu_Breakout_A4988; Pololu_Breakout-16_15.2x20.3mm
Y_Motor_Header1: Conn_01x04; PinHeader_1x04_P2.54mm_Vertical
Z1, Z2: Pololu_Breakout_A4988; Pololu_Breakout-16_15.2x20.3mm
Z1_Motor_Header1, Z2_Motor_Header1: Conn_01x04; PinHeader_1x04_P2.54mm_Vertical

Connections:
+3V3: A6.3V3 (3.3V)
+5V: 24-5v_buckconverter1.3, A6.5V1 (5V), A6.5V3 (5V), A6.5V4 (5V), E1.2 (VDD), E1.10 (MS1), E1.11 (MS2), E1.12 (MS3), LCD_TFT_Pins1.1, X3.2 (VDD), X3.10 (MS1), X3.11 (MS2), X3.12 (MS3), Y3.2 (VDD), Y3.10 (MS1), Y3.11 (MS2), Y3.12 (MS3), Z1.2 (VDD), Z1.10 (MS1), Z1.11 (MS2), Z1.12 (MS3), Z2.2 (VDD), Z2.10 (MS1), Z2.11 (MS2), Z2.12 (MS3)
+24V: 24-5v_buckconverter1.1, C_E1.2, C_Small_E1.2, C_Small_X1.2, C_Small_Y1.2, C_Small_Z1.2, C_Small_Z2.2, C_X1.2, C_Y1.1, C_Z1.2, C_Z2.2, E1.8 (VMOT), HE_Fan_header1.1, He_Heater1.1, Power_Input_24V1.1, X3.8 (VMOT), Y3.8 (VMOT), Z1.8 (VMOT), Z2.8 (VMOT)
GND: 24-5v_buckconverter1.2, 24-5v_buckconverter1.4, A6.GND1 (GND), A6.GND2 (GND), A6.GND3 (GND), A6.GND5 (GND), A6.GND6 (GND), C_E1.1, C_Small_E1.1, C_Small_X1.1, C_Small_Y1.1, C_Small_Z1.1, C_Small_Z2.1, C_X1.1, C_Y1.2, C_Z1.1, C_Z2.1, E1.1 (GND), E1.7 (GND), HE_Fan_header1.2, HE_Heater_MOSFET1.3 (S), HE_Thermistor1.1, LCD_TFT_Pins1.2, Power_Input_24V1.2, Resistor_10k1.2, SW_X1.1, SW_X2.1, SW_Y1.1, SW_Y2.1, SW_Z1.1, SW_Z2.1, X3.1 (GND), X3.7 (GND), Y3.1 (GND), Y3.7 (GND), Z1.1 (GND), Z1.7 (GND), Z2.1 (GND), Z2.7 (GND)
unnamed: A6.D0 (D0/RX0), LCD_TFT_Pins1.3
unnamed: A6.D1 (D1/TX0), LCD_TFT_Pins1.4
unnamed: A6.A15, Resistor_150.2
unnamed: E1.4 (1A), E_Motor_Header1.2
unnamed: E1.3 (1B), E_Motor_Header1.1
unnamed: E1.5 (2A), E_Motor_Header1.3
unnamed: E1.6 (2B), E_Motor_Header1.4
unnamed: A6.D30, E1.16 (DIR)
unnamed: A6.D29, E1.15 (STEP)
unnamed: A6.D28, E1.9 (~ENABLE)
unnamed: E1.13 (~RESET), E1.14 (~SLEEP)
unnamed: HE_Heater_MOSFET1.2 (D), He_Heater1.2
unnamed: HE_Heater_MOSFET1.1 (G), Resistor_10k1.1, Resistor_150.1
unnamed: A6.A0, HE_Thermistor1.2
unnamed: A6.D27, SW_X1.2
unnamed: A6.D26, SW_X2.2
unnamed: A6.D25, SW_Y1.2
unnamed: A6.D24, SW_Y2.2
unnamed: A6.D23, SW_Z1.2
unnamed: A6.D22, SW_Z2.2
unnamed: X3.4 (1A), X_Motor_Header1.2
unnamed: X3.3 (1B), X_Motor_Header1.1
unnamed: X3.5 (2A), X_Motor_Header1.3
unnamed: X3.6 (2B), X_Motor_Header1.4
unnamed: A6.D36, X3.16 (DIR)
unnamed: A6.D35, X3.15 (STEP)
unnamed: A6.D34, X3.9 (~ENABLE)
unnamed: X3.13 (~RESET), X3.14 (~SLEEP)
unnamed: Y3.4 (1A), Y_Motor_Header1.2
unnamed: Y3.3 (1B), Y_Motor_Header1.1
unnamed: Y3.5 (2A), Y_Motor_Header1.3
unnamed: Y3.6 (2B), Y_Motor_Header1.4
unnamed: A6.D39, Y3.16 (DIR)
unnamed: A6.D38, Y3.15 (STEP)
unnamed: A6.D37, Y3.9 (~ENABLE)
unnamed: Y3.13 (~RESET), Y3.14 (~SLEEP)
unnamed: Z1.4 (1A), Z1_Motor_Header1.2
unnamed: Z1.3 (1B), Z1_Motor_Header1.1
unnamed: Z1.5 (2A), Z1_Motor_Header1.3
unnamed: Z1.6 (2B), Z1_Motor_Header1.4
unnamed: A6.D42, Z1.16 (DIR)
unnamed: A6.D41, Z1.15 (STEP)
unnamed: A6.D31, Z1.9 (~ENABLE), Z2.9 (~ENABLE)
unnamed: Z1.13 (~RESET), Z1.14 (~SLEEP)
unnamed: Z2.4 (1A), Z2_Motor_Header1.2
unnamed: Z2.3 (1B), Z2_Motor_Header1.1
unnamed: Z2.5 (2A), Z2_Motor_Header1.3
unnamed: Z2.6 (2B), Z2_Motor_Header1.4
unnamed: A6.D33, Z2.16 (DIR)
unnamed: A6.D32, Z2.15 (STEP)
unnamed: Z2.13 (~RESET), Z2.14 (~SLEEP)

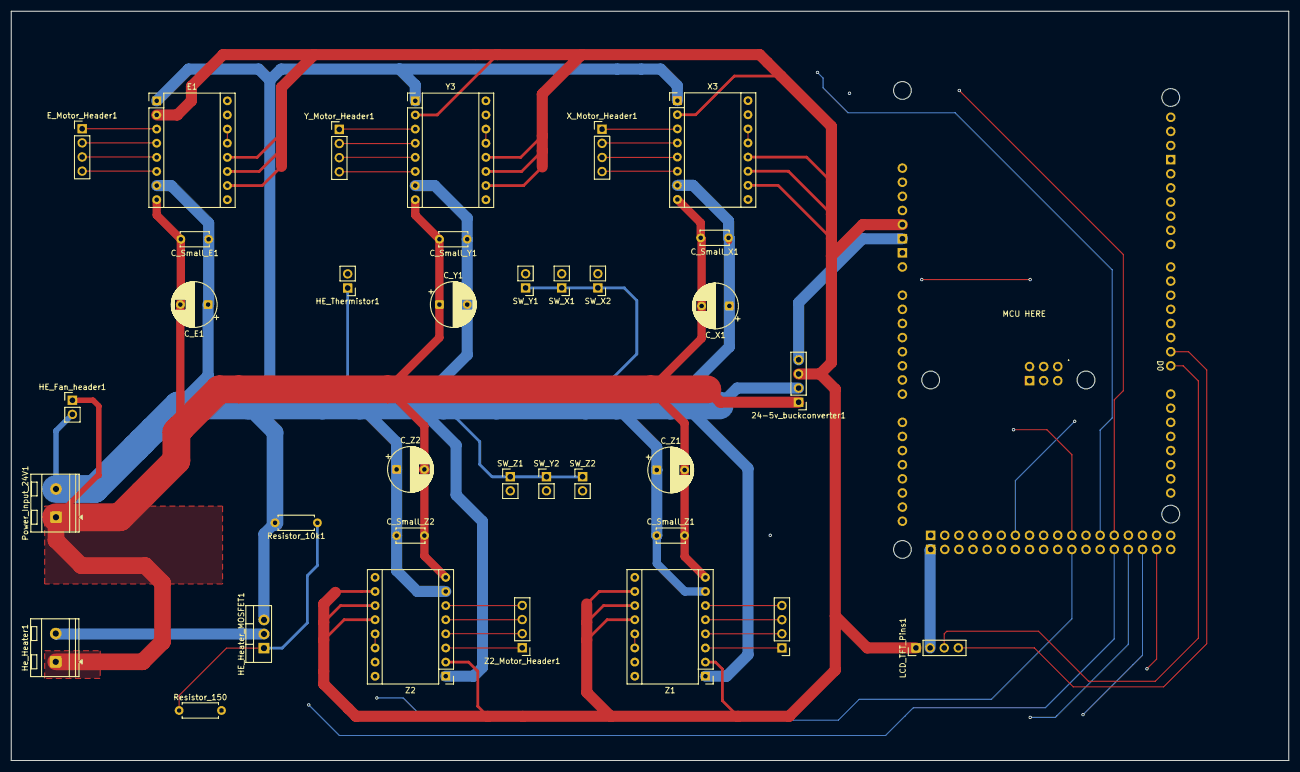
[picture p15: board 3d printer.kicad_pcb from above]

Board: 4 copper layers, 229.8 x 134.8 mm, 36 parts (0 on the bottom side), 54 nets.

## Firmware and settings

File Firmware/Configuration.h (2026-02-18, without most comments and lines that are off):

#pragma once
#define CONFIGURATION_H_VERSION 02010206
#define STRING_CONFIG_H_AUTHOR "(none, default config)" // Who made the changes.
#define SHOW_BOOTSCREEN
  #define MOTHERBOARD BOARD_RAMPS_14_EFB
#define SERIAL_PORT 0
#define BAUDRATE 250000
#define X_DRIVER_TYPE  A4988
#define Y_DRIVER_TYPE  A4988
#define Z_DRIVER_TYPE  A4988
#define E0_DRIVER_TYPE A4988
#define EXTRUDERS 1
#define DEFAULT_NOMINAL_FILAMENT_DIA 1.75
#define TEMP_SENSOR_0 1
#define TEMP_SENSOR_1 0
#define TEMP_SENSOR_2 0
#define TEMP_SENSOR_3 0
#define TEMP_SENSOR_4 0
#define TEMP_SENSOR_5 0
#define TEMP_SENSOR_6 0
#define TEMP_SENSOR_7 0
#define TEMP_SENSOR_BED 1
#define TEMP_SENSOR_PROBE 0
#define TEMP_SENSOR_CHAMBER 0
#define TEMP_SENSOR_COOLER 0
#define TEMP_SENSOR_BOARD 0
#define TEMP_SENSOR_REDUNDANT 0
#define DUMMY_THERMISTOR_998_VALUE  25
#define DUMMY_THERMISTOR_999_VALUE 100
#if TEMP_SENSOR_IS_MAX_TC(0)
  #define MAX31865_SENSOR_OHMS_0      100 // (Ω) Typically 100 or 1000 (PT100 or PT1000)
  #define MAX31865_CALIBRATION_OHMS_0 430 // (Ω) Typically 430 for Adafruit PT100; 4300 for Adafruit PT1000
#endif
#if TEMP_SENSOR_IS_MAX_TC(1)
  #define MAX31865_SENSOR_OHMS_1      100
  #define MAX31865_CALIBRATION_OHMS_1 430
#endif
#if TEMP_SENSOR_IS_MAX_TC(2)
  #define MAX31865_SENSOR_OHMS_2      100
  #define MAX31865_CALIBRATION_OHMS_2 430
#endif
#if HAS_E_TEMP_SENSOR
  #define TEMP_RESIDENCY_TIME         10  // (seconds) Time to wait for hotend to "settle" in M109
  #define TEMP_WINDOW                  1  // (°C) Temperature proximity for the "temperature reached" timer
  #define TEMP_HYSTERESIS              3  // (°C) Temperature proximity considered "close enough" to the target
#endif
#if TEMP_SENSOR_BED
  #define TEMP_BED_RESIDENCY_TIME     10  // (seconds) Time to wait for bed to "settle" in M190
  #define TEMP_BED_WINDOW              1  // (°C) Temperature proximity for the "temperature reached" timer
  #define TEMP_BED_HYSTERESIS          3  // (°C) Temperature proximity considered "close enough" to the target
#endif
#if TEMP_SENSOR_CHAMBER
  #define TEMP_CHAMBER_RESIDENCY_TIME 10  // (seconds) Time to wait for chamber to "settle" in M191
  #define TEMP_CHAMBER_WINDOW          1  // (°C) Temperature proximity for the "temperature reached" timer
  #define TEMP_CHAMBER_HYSTERESIS      3  // (°C) Temperature proximity considered "close enough" to the target
#endif
#if TEMP_SENSOR_REDUNDANT
  #define TEMP_SENSOR_REDUNDANT_SOURCE    E1  // The sensor that will provide the redundant reading.
  #define TEMP_SENSOR_REDUNDANT_TARGET    E0  // The sensor that we are providing a redundant reading for.
  #define TEMP_SENSOR_REDUNDANT_MAX_DIFF  10  // (°C) Temperature difference that will trigger a print abort.
#endif
#define HEATER_0_MINTEMP   5
#define HEATER_1_MINTEMP   5
#define HEATER_2_MINTEMP   5
#define HEATER_3_MINTEMP   5
#define HEATER_4_MINTEMP   5
#define HEATER_5_MINTEMP   5
#define HEATER_6_MINTEMP   5
#define HEATER_7_MINTEMP   5
#define BED_MINTEMP        5
#define CHAMBER_MINTEMP    5
#define HEATER_0_MAXTEMP 275
#define HEATER_1_MAXTEMP 275
#define HEATER_2_MAXTEMP 275
#define HEATER_3_MAXTEMP 275
#define HEATER_4_MAXTEMP 275
#define HEATER_5_MAXTEMP 275
#define HEATER_6_MAXTEMP 275
#define HEATER_7_MAXTEMP 275
#define BED_MAXTEMP      150
#define CHAMBER_MAXTEMP  60
#define HOTEND_OVERSHOOT 15   // (°C) Forbid temperatures over MAXTEMP - OVERSHOOT
#define BED_OVERSHOOT    10   // (°C) Forbid temperatures over MAXTEMP - OVERSHOOT
#define COOLER_OVERSHOOT  2   // (°C) Forbid temperatures closer than OVERSHOOT
#define PIDTEMP           // See the PID Tuning Guide at https://reprap.org/wiki/PID_Tuning
#define PID_MAX  255      // Limit hotend current while PID is active (see PID_FUNCTIONAL_RANGE below); 255=full current
#define PID_K1     0.95   // Smoothing factor within any PID loop
    #define DEFAULT_KP  22.20
    #define DEFAULT_KI   1.08
    #define DEFAULT_KD 114.00
#define MAX_BED_POWER 255 // limits duty cycle to bed; 255=full current
#define MAX_CHAMBER_POWER 255 // limits duty cycle to chamber heater; 255=full current
  #define PID_FUNCTIONAL_RANGE 10 // If the temperature difference between the target temperature and the actual temperature
#define PREVENT_COLD_EXTRUSION
#define EXTRUDE_MINTEMP 170
#define PREVENT_LENGTHY_EXTRUDE
#define EXTRUDE_MAXLENGTH 200
#define THERMAL_PROTECTION_HOTENDS // Enable thermal protection for all extruders
#define THERMAL_PROTECTION_BED     // Enable thermal protection for the heated bed
#define THERMAL_PROTECTION_CHAMBER // Enable thermal protection for the heated chamber
#define THERMAL_PROTECTION_COOLER  // Enable thermal protection for the laser cooling
#define USE_XMIN_PLUG
#define USE_YMIN_PLUG
#define USE_ZMIN_PLUG
#define ENDSTOPPULLUPS
#define X_MIN_ENDSTOP_INVERTING false // Set to true to invert the logic of the endstop.
#define Y_MIN_ENDSTOP_INVERTING false // Set to true to invert the logic of the endstop.
#define Z_MIN_ENDSTOP_INVERTING false // Set to true to invert the logic of the endstop.
#define I_MIN_ENDSTOP_INVERTING false // Set to true to invert the logic of the endstop.
#define J_MIN_ENDSTOP_INVERTING false // Set to true to invert the logic of the endstop.
#define K_MIN_ENDSTOP_INVERTING false // Set to true to invert the logic of the endstop.
#define U_MIN_ENDSTOP_INVERTING false // Set to true to invert the logic of the endstop.
#define V_MIN_ENDSTOP_INVERTING false // Set to true to invert the logic of the endstop.
#define W_MIN_ENDSTOP_INVERTING false // Set to true to invert the logic of the endstop.
#define X_MAX_ENDSTOP_INVERTING false // Set to true to invert the logic of the endstop.
#define Y_MAX_ENDSTOP_INVERTING false // Set to true to invert the logic of the endstop.
#define Z_MAX_ENDSTOP_INVERTING false // Set to true to invert the logic of the endstop.
#define I_MAX_ENDSTOP_INVERTING false // Set to true to invert the logic of the endstop.
#define J_MAX_ENDSTOP_INVERTING false // Set to true to invert the logic of the endstop.
#define K_MAX_ENDSTOP_INVERTING false // Set to true to invert the logic of the endstop.
#define U_MAX_ENDSTOP_INVERTING false // Set to true to invert the logic of the endstop.
#define V_MAX_ENDSTOP_INVERTING false // Set to true to invert the logic of the endstop.
#define W_MAX_ENDSTOP_INVERTING false // Set to true to invert the logic of the endstop.
#define Z_MIN_PROBE_ENDSTOP_INVERTING false // Set to true to invert the logic of the probe.
#define DEFAULT_AXIS_STEPS_PER_UNIT   { 80, 80, 400, 500 }
#define DEFAULT_MAX_FEEDRATE          { 300, 300, 5, 25 }
#define DEFAULT_MAX_ACCELERATION      { 3000, 3000, 100, 10000 }
#define DEFAULT_ACCELERATION          3000    // X, Y, Z and E acceleration for printing moves
#define DEFAULT_RETRACT_ACCELERATION  3000    // E acceleration for retracts
#define DEFAULT_TRAVEL_ACCELERATION   3000    // X, Y, Z acceleration for travel (non printing) moves
#define DEFAULT_EJERK    5.0  // May be used by Linear Advance
  #define JUNCTION_DEVIATION_MM 0.013 // (mm) Distance from real junction edge
  #define JD_HANDLE_SMALL_SEGMENTS    // Use curvature estimation instead of just the junction angle
#define Z_MIN_PROBE_USES_Z_MIN_ENDSTOP_PIN
#define NOZZLE_TO_PROBE_OFFSET { 10, 10, 0 }
#define PROBING_MARGIN 10
#define XY_PROBE_FEEDRATE (133*60)
#define Z_PROBE_FEEDRATE_FAST (4*60)
#define Z_PROBE_FEEDRATE_SLOW (Z_PROBE_FEEDRATE_FAST / 2)
#define Z_CLEARANCE_DEPLOY_PROBE   10 // (mm) Z Clearance for Deploy/Stow
#define Z_CLEARANCE_BETWEEN_PROBES  5 // (mm) Z Clearance between probe points
#define Z_CLEARANCE_MULTI_PROBE     5 // (mm) Z Clearance between multiple probes
#define Z_PROBE_LOW_POINT          -2 // (mm) Farthest distance below the trigger-point to go before stopping
#define Z_PROBE_OFFSET_RANGE_MIN -20
#define Z_PROBE_OFFSET_RANGE_MAX 20
#define X_ENABLE_ON 0
#define Y_ENABLE_ON 0
#define Z_ENABLE_ON 0
#define E_ENABLE_ON 0 // For all extruders
#define DISABLE_OTHER_EXTRUDERS   // Keep only the active extruder enabled
#define INVERT_X_DIR false
#define INVERT_Y_DIR true
#define INVERT_Z_DIR false
#define INVERT_E0_DIR false
#define INVERT_E1_DIR false
#define INVERT_E2_DIR false
#define INVERT_E3_DIR false
#define INVERT_E4_DIR false
#define INVERT_E5_DIR false
#define INVERT_E6_DIR false
#define INVERT_E7_DIR false
#define X_HOME_DIR -1
#define Y_HOME_DIR -1
#define Z_HOME_DIR -1
#define X_BED_SIZE 200
#define Y_BED_SIZE 200
#define X_MIN_POS 0
#define Y_MIN_POS 0
#define Z_MIN_POS 0
#define X_MAX_POS X_BED_SIZE
#define Y_MAX_POS Y_BED_SIZE
#define Z_MAX_POS 200
#define MIN_SOFTWARE_ENDSTOPS
  #define MIN_SOFTWARE_ENDSTOP_X
  #define MIN_SOFTWARE_ENDSTOP_Y
  #define MIN_SOFTWARE_ENDSTOP_Z
  #define MIN_SOFTWARE_ENDSTOP_I
  #define MIN_SOFTWARE_ENDSTOP_J
  #define MIN_SOFTWARE_ENDSTOP_K
  #define MIN_SOFTWARE_ENDSTOP_U
  #define MIN_SOFTWARE_ENDSTOP_V
  #define MIN_SOFTWARE_ENDSTOP_W
#define MAX_SOFTWARE_ENDSTOPS
  #define MAX_SOFTWARE_ENDSTOP_X
  #define MAX_SOFTWARE_ENDSTOP_Y
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

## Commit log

2025-12-29 Added BOM
    [3d Printer BOM - Sheet1.csv]
2025-12-29 Update 3d Printer BOM - Sheet1.csv
    [3d Printer BOM - Sheet1.csv]
2026-01-05 Update and rename 3d printer.kicad_pcb to PCB/3d printer.kicad_pcb
    [3d printer.kicad_pcb]
2026-01-05 Rename 3d printer.kicad_prl to PCB/3d printer.kicad_prl
2026-01-05 Rename 3d printer.kicad_pro to PCB/3d printer.kicad_pro
2026-01-05 Update and rename 3d printer.kicad_sch to PCB/3d printer.kicad_sch
    [3d printer.kicad_sch]
2026-01-05 Rename Complete printer assembly.f3z to Assembly/Complete printer assembly.f3z
    [Complete printer assembly.f3z]
2026-01-05 Rename Complete printer assembly.step to Assembly/Complete printer assembly.step
    [Complete printer assembly.step]
2026-01-05 Rename Complete printer assembly.zip to Assembly/Complete printer assembly.zip
2026-01-05 Update and rename Extruder coupling.step to CAD/Extruder coupling.step
    [Extruder coupling.step]
2026-01-05 Update and rename Extruder mechanism.step to CAD/Extruder mechanism.step
    [Extruder mechanism.step]
2026-01-05 Update and rename Toolhead.step to CAD/Toolhead.step
    [Toolhead.step]
2026-01-05 Update and rename X carriage print file.step to CAD/X carriage print file.step
    [X carriage print file.step]
2026-01-05 Update and rename Y carriage idler print file.step to CAD/Y carriage idler print file.step
    [Y carriage idler print file.step]
2026-01-05 Update and rename Y carriage stepper motor print file.step to CAD/Y carriage stepper motor print file.step
    [Y carriage stepper motor print file.step]
2026-01-05 Update and rename Z axis bearing clamp print file.step to CAD/Z axis bearing clamp print file.step
    [Z axis bearing clamp print file.step]
2026-01-05 Update and rename Z smooth rod holder.step to CAD/Z smooth rod holder.step
    [Z smooth rod holder.step]
2026-01-05 Update and rename Z stepper bracket print file.step to CAD/Z stepper bracket print file.step
    [Z stepper bracket print file.step]
2026-02-18 Rename Printer assembly step.zip to CAD/Printer assembly step.zip

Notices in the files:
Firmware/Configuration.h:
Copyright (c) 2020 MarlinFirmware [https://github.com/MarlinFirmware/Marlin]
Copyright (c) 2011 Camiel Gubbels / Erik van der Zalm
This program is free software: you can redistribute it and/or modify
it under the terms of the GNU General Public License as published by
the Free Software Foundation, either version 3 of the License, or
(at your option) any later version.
